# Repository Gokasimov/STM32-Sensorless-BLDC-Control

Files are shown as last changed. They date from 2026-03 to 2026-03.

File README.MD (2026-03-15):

# Sensorless BLDC Motor Controller (STM32G431RBT6)

Motor Demonstration

## 📌 Overview
This repository contains the complete hardware and firmware design for a **Sensorless 6-Step Trapezoidal BLDC Motor Controller** built around the STM32G4 microcontroller. The project demonstrates advanced embedded motor control techniques, including Back-EMF (BEMF) Zero-Crossing Detection (ZCD) via Injected ADCs, hardware-synchronized timers, and a custom-tuned PI speed controller.

The hardware was designed from scratch (KiCad) and tested rigorously to evaluate both physical limits (Voltage Saturation/Kv limits) and embedded software constraints (Timer Quantization limits).

---

## ⚙️ Firmware Architecture & Control Theory

The firmware avoids blocking delays and polling. It relies entirely on a deterministic, interrupt-driven architecture utilizing STM32 Advanced Timers and ADC peripherals.

### 1. Robust State-Machine
The motor control flow is managed by a strict state machine to ensure safe start-up and running conditions:
* **IDLE:** PWM outputs are disabled (Soft Stop / Coasting).
* **ALIGN:** A static DC magnetic field is applied to the stator to force the mechanical rotor into a known starting position.
* **RAMP-UP:** Open-loop commutation with progressively decreasing delay to generate enough initial BEMF for the ADCs to read.
* **CLOSED-LOOP:** Sensorless commutation takes over. The system relies purely on ZCD events and the PI controller manages the PWM duty cycle to reach the target RPM.
* **FAULT:** Emergency hard-stop triggered by stall detection or hardware limits.

### 2. Injected ADC & Timer Synchronization
To avoid high-frequency PWM switching noise (ringing), BEMF is **not** polled continuously in the main loop. Instead, the STM32's **Injected ADC** channels are hardware-triggered by `TIM1`'s Update/Compare events. 
This ensures that the BEMF voltage is sampled exactly at the optimal moment (typically the PWM ON state or center-aligned peak), providing a clean signal for the ZCD algorithm without requiring heavy software filtering.

### 3. PI Speed Control & Super-Sampling (MAF)
Speed calculation at high RPMs suffers from timer resolution limits (Quantization Error). To mitigate this without using floating-point math on every cycle, a **Moving Average Filter (MAF)** is implemented.
The PI controller runs deterministically in a dedicated 1kHz timer interrupt (`TIM7`). It compares the filtered RPM against the target and smoothly adjusts the duty cycle, featuring anti-windup clamping to protect the system.

---

## 🔬 Key Hardware Verifications

Theoretical models were strictly validated against physical hardware behavior using a 4-channel oscilloscope and RAM data logging. *(For full oscilloscope captures, including Dead-Time verification, please see the [Results/](./Results) folder).*

### 1. Hardware RC Filter Phase Shift & ZCD Smoothing
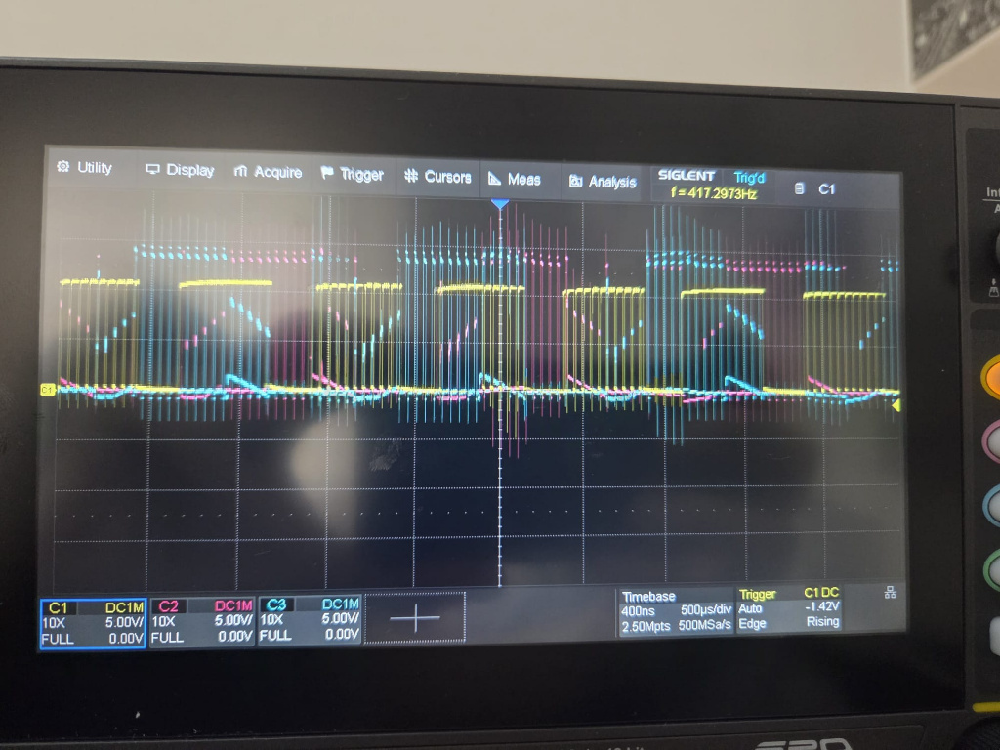
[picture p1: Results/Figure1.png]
ZCD Proof

> **Analysis:** The Yellow trace shows the raw Phase 1 voltage. The Blue trace shows the signal at the STM32 ADC pin after the resistor divider and RC filter. The filter successfully eliminates PWM noise. Crucially, the inherent RC time delay acts as a natural "Phase Advance," optimizing high-speed commutation timing directly in hardware, eliminating the need for 30-degree software compensation.

### 2. System Limit Discovery (RAM Datalogging)
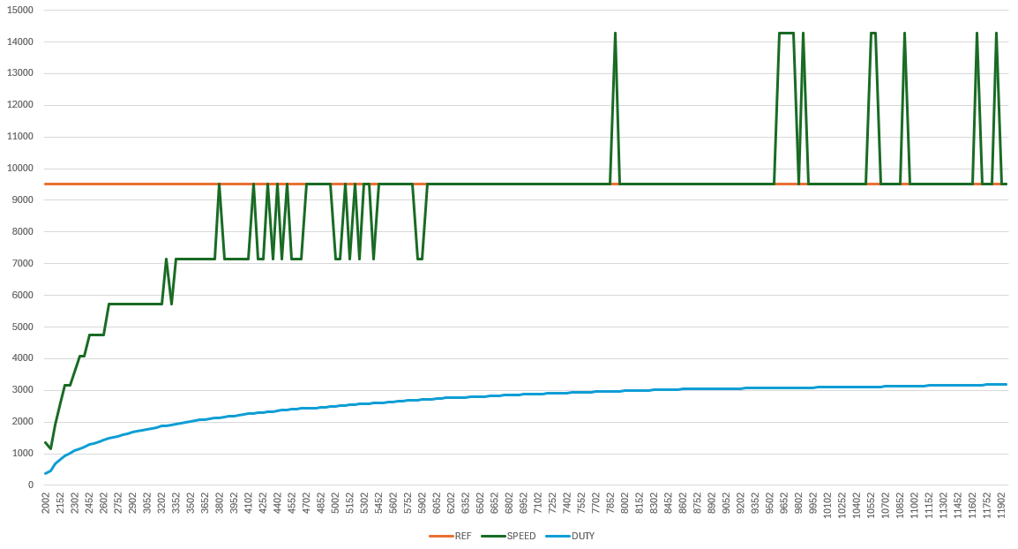
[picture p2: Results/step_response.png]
Step Response

> **Analysis (Step Response & Limitations):** Extracted via an 8KB internal RAM "Flight Recorder" to avoid UART bottlenecking. The graph reveals two physical realities:
> * **Voltage Saturation:** The PI controller pushes the Duty Cycle (Green) to its ~95% limit to reach 14200 RPM, but the motor plateaus at ~9500 RPM (Orange). The motor has hit its BEMF ceiling for a 12V supply ($\Delta V \approx 0$).
> * **Quantization Artifacts:** The step-like jumps at peak speeds are not physical. They are artifacts of the 50us timer resolution; at extreme speeds, a 1-tick variation in commutation measurement results in massive calculated RPM swings, proving the necessity of the MAF implemented in the code.

---

## 🔌 Quick Start & Hardware Setup

### Custom Hardware Notes (v1.0 Prototyping)
* **MP1482 Bypass:** Due to a layout errata on the v1.0 PCB, the onboard 12V-to-3.3V buck converter is bypassed. Logic power is supplied externally. (See `Hardware/ERRATA.md` for details).
* **Future-Proofing (DNP):** The board includes footprints for inline current shunts, op-amps, and encoder headers. These are currently marked as DNP (Do Not Populate) as they are reserved for the upcoming FOC (Field Oriented Control) revision.

## 📁 Repository Structure

📦 STM32-Sensorless-BLDC-Control
 ┣ 📂 Firmware         # STM32CubeIDE Project (C source, headers, .ioc)
 ┣ 📂 Hardware         # KiCad project, Schematics (PDF), BOM, and Errata
 ┣ 📂 Results          # Oscilloscope captures and Step Response graphs
 ┣ 📜 .gitignore       # Excludes IDE debug/build binaries
 ┣ 📜 README.md        # You are here
 ┗ 📜 LICENSE          # MIT License

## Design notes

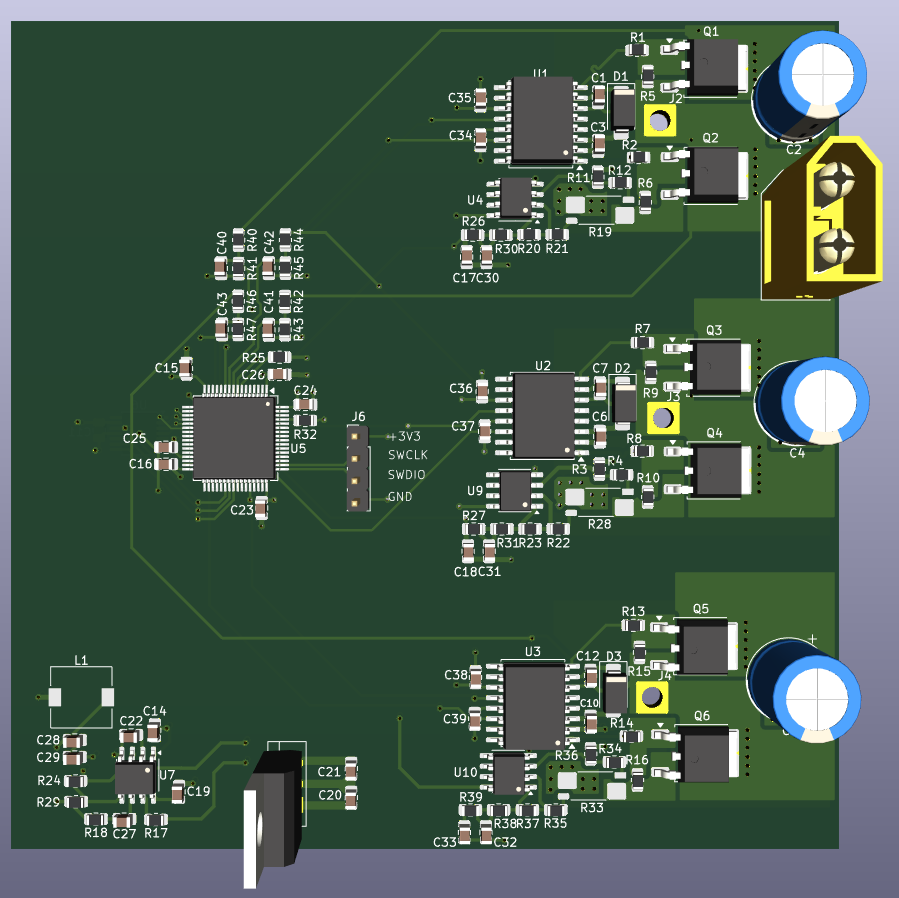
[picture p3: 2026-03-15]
Hardware/Board2_3DView.png

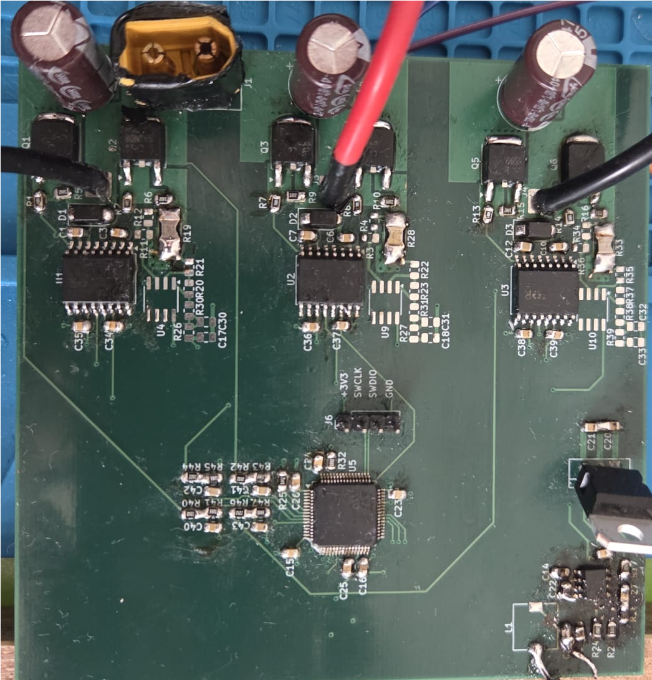
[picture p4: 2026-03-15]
Hardware/Board2.png

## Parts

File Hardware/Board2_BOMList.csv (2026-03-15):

Reference | Qty | Value | Footprint
C1,C7,C12,C20,C21 | 5 | 1uF | Capacitor_SMD:C_0805_2012Metric
C2,C4,C5 | 3 | 470u | Capacitor_THT:CP_Radial_D10.0mm_P5.00mm
C3,C6,C10,C11,C15,C16,C23,C24,C25,C26,C34,C35,C36,C37,C38,C39 | 16 | 0.1uF | Capacitor_SMD:C_0805_2012Metric
C8,C9,C13 | 3 | 1n | Capacitor_SMD:C_0805_2012Metric
C14 | 1 | 10n | Capacitor_SMD:C_0805_2012Metric
C17,C18,C30,C31,C32,C33 | 6 | 33nF | Capacitor_SMD:C_0805_2012Metric
C19 | 1 | 0.1u | Capacitor_SMD:C_0805_2012Metric
C22 | 1 | 10u | Capacitor_SMD:C_0805_2012Metric
C27 | 1 | 3.3n | Capacitor_SMD:C_0805_2012Metric
C28,C29 | 2 | 22n | Capacitor_SMD:C_0805_2012Metric
C40,C41,C42,C43 | 4 | 100n | Capacitor_SMD:C_0805_2012Metric
D1,D2,D3 | 3 | SS14 | Diode_SMD:D_SMA
J1 | 1 | Conn_01x02_Pin | Connector_AMASS:AMASS_XT60-F_1x02_P7.20mm_Vertical
J2,J3,J4 | 3 | Conn_01x01_Pin | Connector_Wire:SolderWire-2sqmm_1x01_D2mm_OD3.9mm
J6 | 1 | Conn_01x04_Pin | Connector_PinHeader_2.54mm:PinHeader_1x04_P2.54mm_Vertical
L1 | 1 | 10u | Inductor_SMD:L_7.3x7.3_H3.5
Q1,Q2,Q3,Q4,Q5,Q6 | 6 | panjit-pjd80n06sa-au | Package_TO_SOT_SMD:TO-252-2
R1,R2,R7,R8,R13,R14 | 6 | 10 | Resistor_SMD:R_0805_2012Metric
R3,R11,R36 | 3 | 22k | Resistor_SMD:R_0805_2012Metric
R4,R12,R21,R22,R34,R35 | 6 | 1k | Resistor_SMD:R_0805_2012Metric
R5,R6,R9,R10,R15,R16,R29 | 7 | 10k | Resistor_SMD:R_0805_2012Metric
R17 | 1 | 100k | Resistor_SMD:R_0805_2012Metric
R18 | 1 | 5.6k | Resistor_SMD:R_0805_2012Metric
R19,R28,R33 | 3 | 5m | Resistor_SMD:R_Shunt_Vishay_WSK2512_6332Metric_T1.19mm
R20,R23,R37 | 3 | 24k | Resistor_SMD:R_0805_2012Metric
R24 | 1 | 26.1k | Resistor_SMD:R_0805_2012Metric
R25,R32 | 2 | 10K | Resistor_SMD:R_0805_2012Metric
R26,R27,R39 | 3 | 270 | Resistor_SMD:R_0805_2012Metric
R30,R31,R38 | 3 | 22 | Resistor_SMD:R_0805_2012Metric
R40,R42,R44,R46 | 4 | 22K | Resistor_SMD:R_0805_2012Metric
R41,R43,R45,R47 | 4 | 3.3K | Resistor_SMD:R_0805_2012Metric
U1,U2,U3 | 3 | IR2110S | Package_SO:SOIC-16W_7.5x10.3mm_P1.27mm
U4,U9,U10 | 3 | TLV9062 | Package_SO:SOIC-8_3.9x4.9mm_P1.27mm | DNP
U5 | 1 | STM32G431RBT6 | Package_QFP:LQFP-64_10x10mm_P0.5mm
U6 | 1 | AS5047D | Package_SO:TSSOP-14_4.4x5mm_P0.65mm | DNP
U7 | 1 | MP1482DS-LF-Z | Package_SO:SOIC-8_3.9x4.9mm_P1.27mm
U8 | 1 | LM7812_TO220 | Package_TO_SOT_THT:TO-220-3_Vertical

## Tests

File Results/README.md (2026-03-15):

# Hardware Verification and Oscilloscope Measurements

This directory contains the raw hardware validation data for the v1.0 Sensorless BLDC controller. Measurements were taken using a 4-channel Siglent SDS814X oscilloscope.

### 1. 3-Phase Commutation Waveforms
3 Phase Commutation
> **Figure 1:** The oscilloscope capture demonstrates the successful 6-step trapezoidal control of the BLDC motor. The 120-degree electrical phase shift is clearly visible. PWM chopping is active during the ON states, while the un-driven phase clearly shows the rising and falling slopes of the Back-EMF, confirming a healthy sensorless operation.

### 2. Hardware RC Filter Phase Shift & ZCD Smoothing
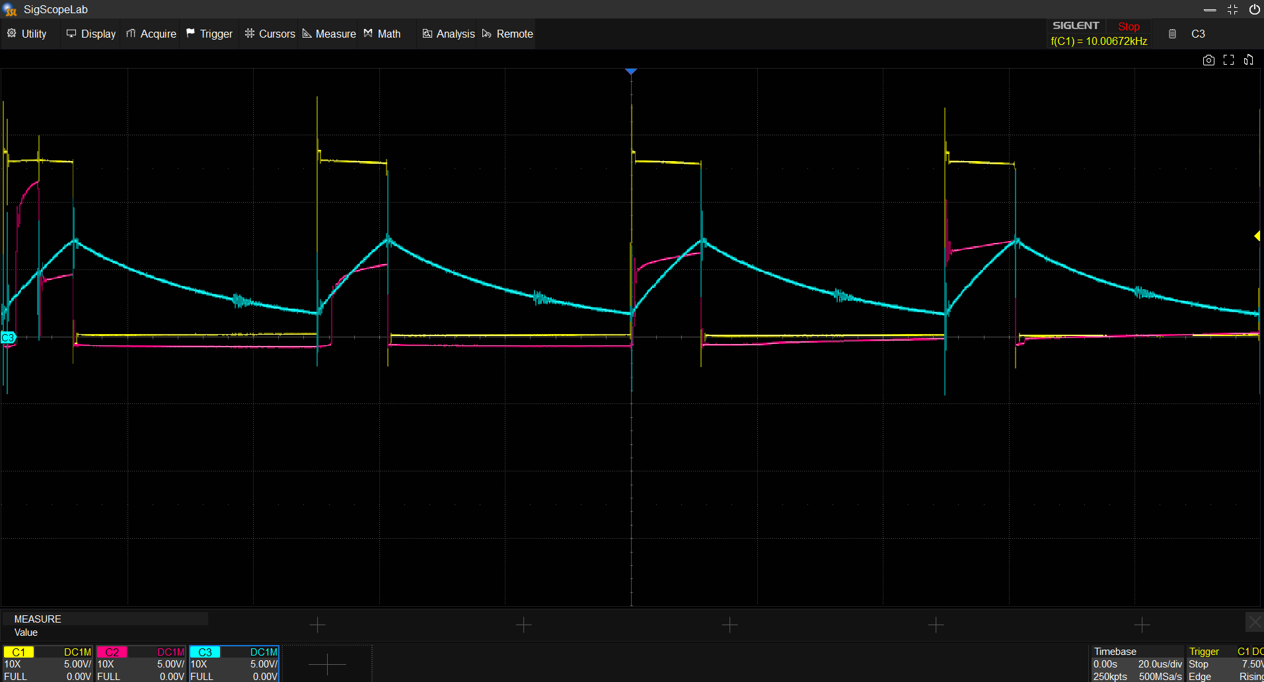
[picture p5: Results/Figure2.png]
ZCD Proof

> **Figure 2:** Yellow trace shows the raw Phase 1 voltage with high-frequency PWM switching. The Blue trace shows the signal at the STM32 ADC pin after the resistor divider and RC filter. The filter successfully eliminates PWM noise, providing a clean BEMF zero-crossing point. The inherent RC time delay acts as a natural "Phase Advance," optimizing high-speed commutation timing without requiring extra MCU processing overhead.

### 3. Hardware Dead-Time Insertion
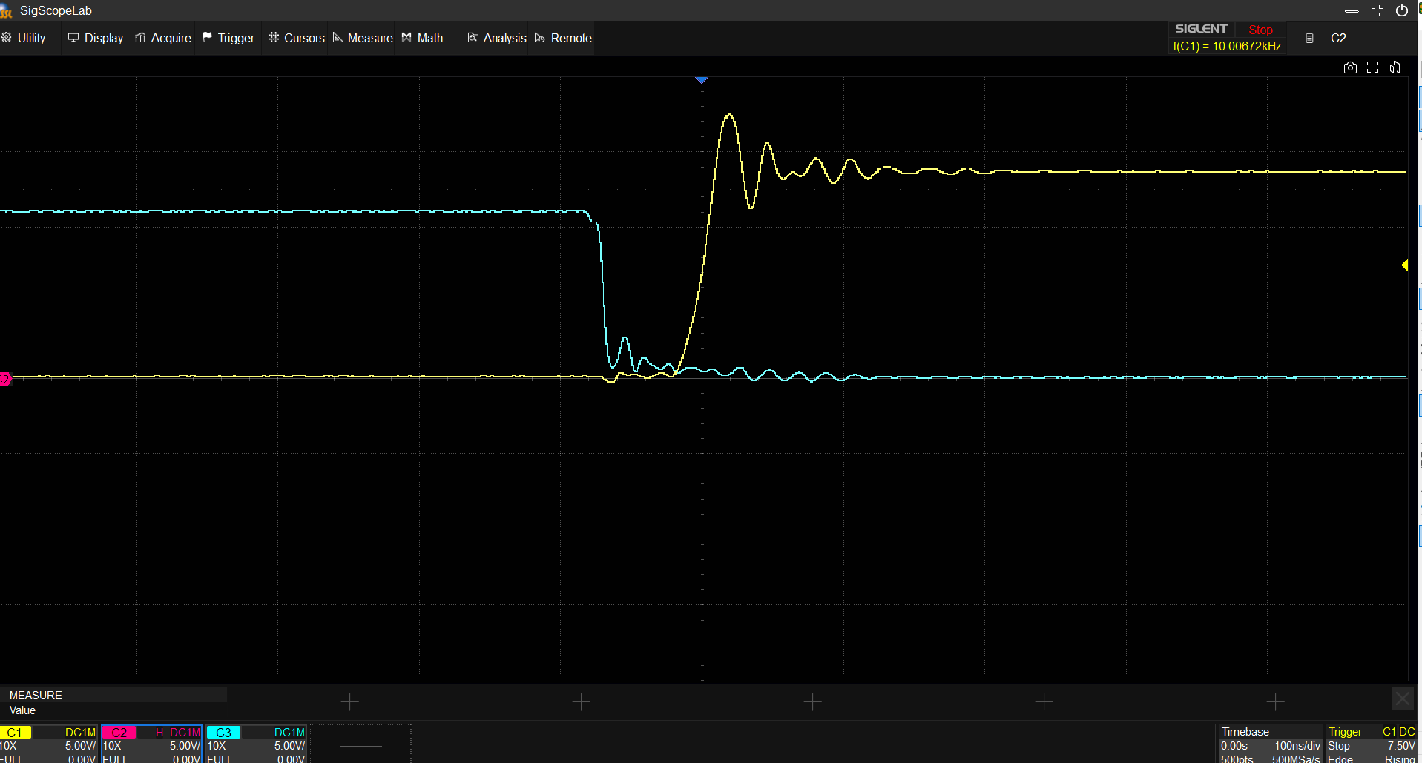
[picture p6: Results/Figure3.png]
Dead Time

> **Figure 3:** Captured at a 100ns/div timebase, this image verifies the STM32 Advanced Timer (TIM1) dead-time generation. A crucial ~100ns gap is maintained between the turn-off of one state and the turn-on of the next. This strictly prevents shoot-through currents in the half-bridges, ensuring the gate drivers and power MOSFETs operate within safe thermal limits.

### 4. BEMF Voltage Saturation at Maximum RPM
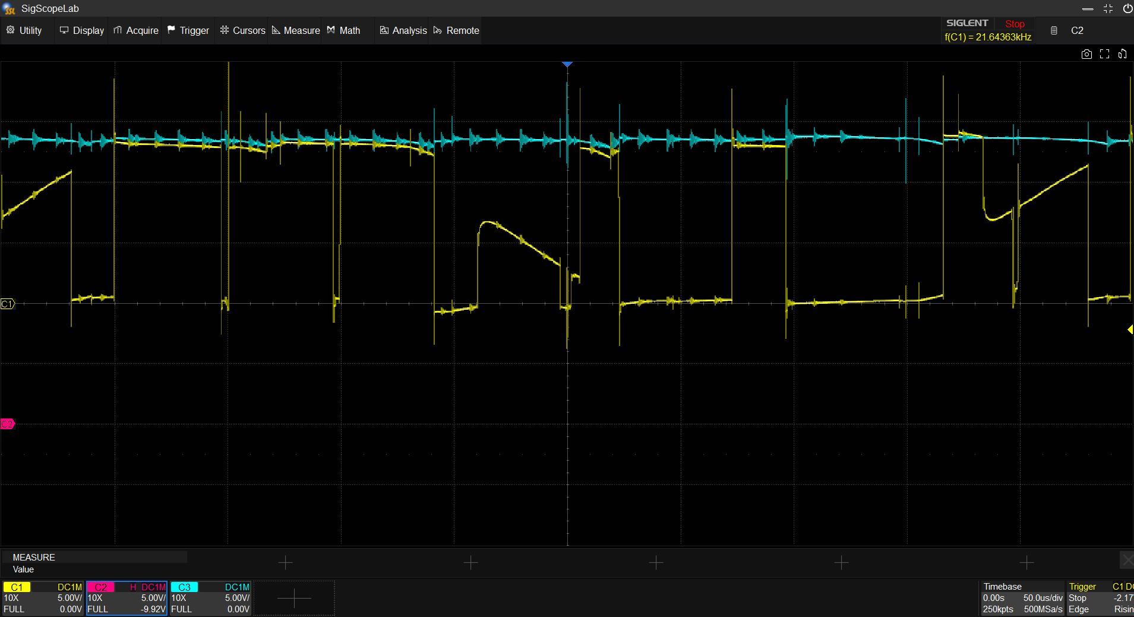
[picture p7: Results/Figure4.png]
Voltage Saturation

> **Figure 4:** The Yellow trace (Phase 1 BEMF) peak approaches the Blue trace (12V DC Link Supply). This proves that the PI controller has saturated the PWM duty cycle to its maximum limit. The motor has reached its physical Kv ceiling for a 12V supply; further acceleration is impossible as ΔV ≈ 0.

### 5. Step Response and System Limit Analysis (RAM Datalog)
Step Response
> **Figure 5: Closed-Loop Telemetry Data Extracted via RAM Datalogging.**
> This plot reveals two critical system boundaries:
> 1. **Voltage Saturation (Physical Limit):** The PI controller smoothly ramps the Duty Cycle (Green) to its absolute maximum (~95%) trying to reach the 14200 RPM reference (Blue). However, the actual speed (Orange) plateaus at ~9500 RPM. This perfectly corroborates the oscilloscope measurement in Figure 4; the motor has hit its 12V BEMF ceiling.
> 2. **Quantization Limit (Software Limit):** The step-like nature of the RPM curve and the high-frequency spikes at the end are not mechanical oscillations. They are artifacts of Timer resolution (Quantization Error). At extreme speeds, the commutation period drops to merely 2 or 3 timer ticks (50us/tick). A variation of just 1 tick (due to ZCD noise) causes the calculated RPM to jump drastically (e.g., 28571/3 = 9523 RPM vs 28571/2 = 14285 RPM).

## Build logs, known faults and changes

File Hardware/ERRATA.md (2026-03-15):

# Hardware Errata and Implementation Notes (v1.0 Prototype)

This document outlines the known hardware issues, temporary workarounds, and unpopulated components for the v1.0 revision of the Sensorless BLDC Motor Controller board. 

As this is an initial lab-tested R&D prototype, some sections have been modified post-production to ensure stable operation of the core motor control algorithms.

## 1. MP1482 Buck Converter Circuit (Bypassed)
* **Description:** A layout/design error was identified in the onboard MP1482 step-down converter section during the initial board bring-up.
* **Workaround:** The onboard voltage regulation section is currently bypassed to prevent power instability. System logic voltage (3.3V for MCU) is temporarily provided via external laboratory power supplies using direct flying leads (bodge wires) soldered to the respective power planes.
* **Impact:** This issue only affects the standalone power capability of the board. It does **not** affect the MCU performance, gate driver switching logic, or the BEMF sensing circuitry. The sensorless 6-step commutation algorithms function perfectly under this bypassed configuration.
* **Resolution:** The buck converter layout will be completely revised in the v1.1 hardware update.

## 2. DNP (Do Not Populate) Components - Future FOC Prep
* **Description:** The PCB was strategically designed to be forward-compatible with advanced motor control techniques. It includes footprints for phase current sensing (inline/low-side shunt resistors and operational amplifiers) as well as header pins for quadrature encoders.
* **Current Status:** Since this specific repository focuses entirely on **Sensorless 6-Step Trapezoidal Control** utilizing Back-EMF Zero-Crossing Detection (ZCD), these specific components are intentionally left unpopulated (DNP) to reduce noise and BOM cost.
* **Future Use:** These analog measurement sections are reserved and will be populated for the upcoming Field Oriented Control (FOC) phase of the project.

## 3. General Prototyping Notes
* Visible flux residues and external wire modifications on the physical board are normal artifacts of the debugging and tuning process for this v1.0 iteration. The primary focus of this hardware version is to validate the STM32G4's ADC Injected Conversion, Timer synchronizations, and hardware limits.

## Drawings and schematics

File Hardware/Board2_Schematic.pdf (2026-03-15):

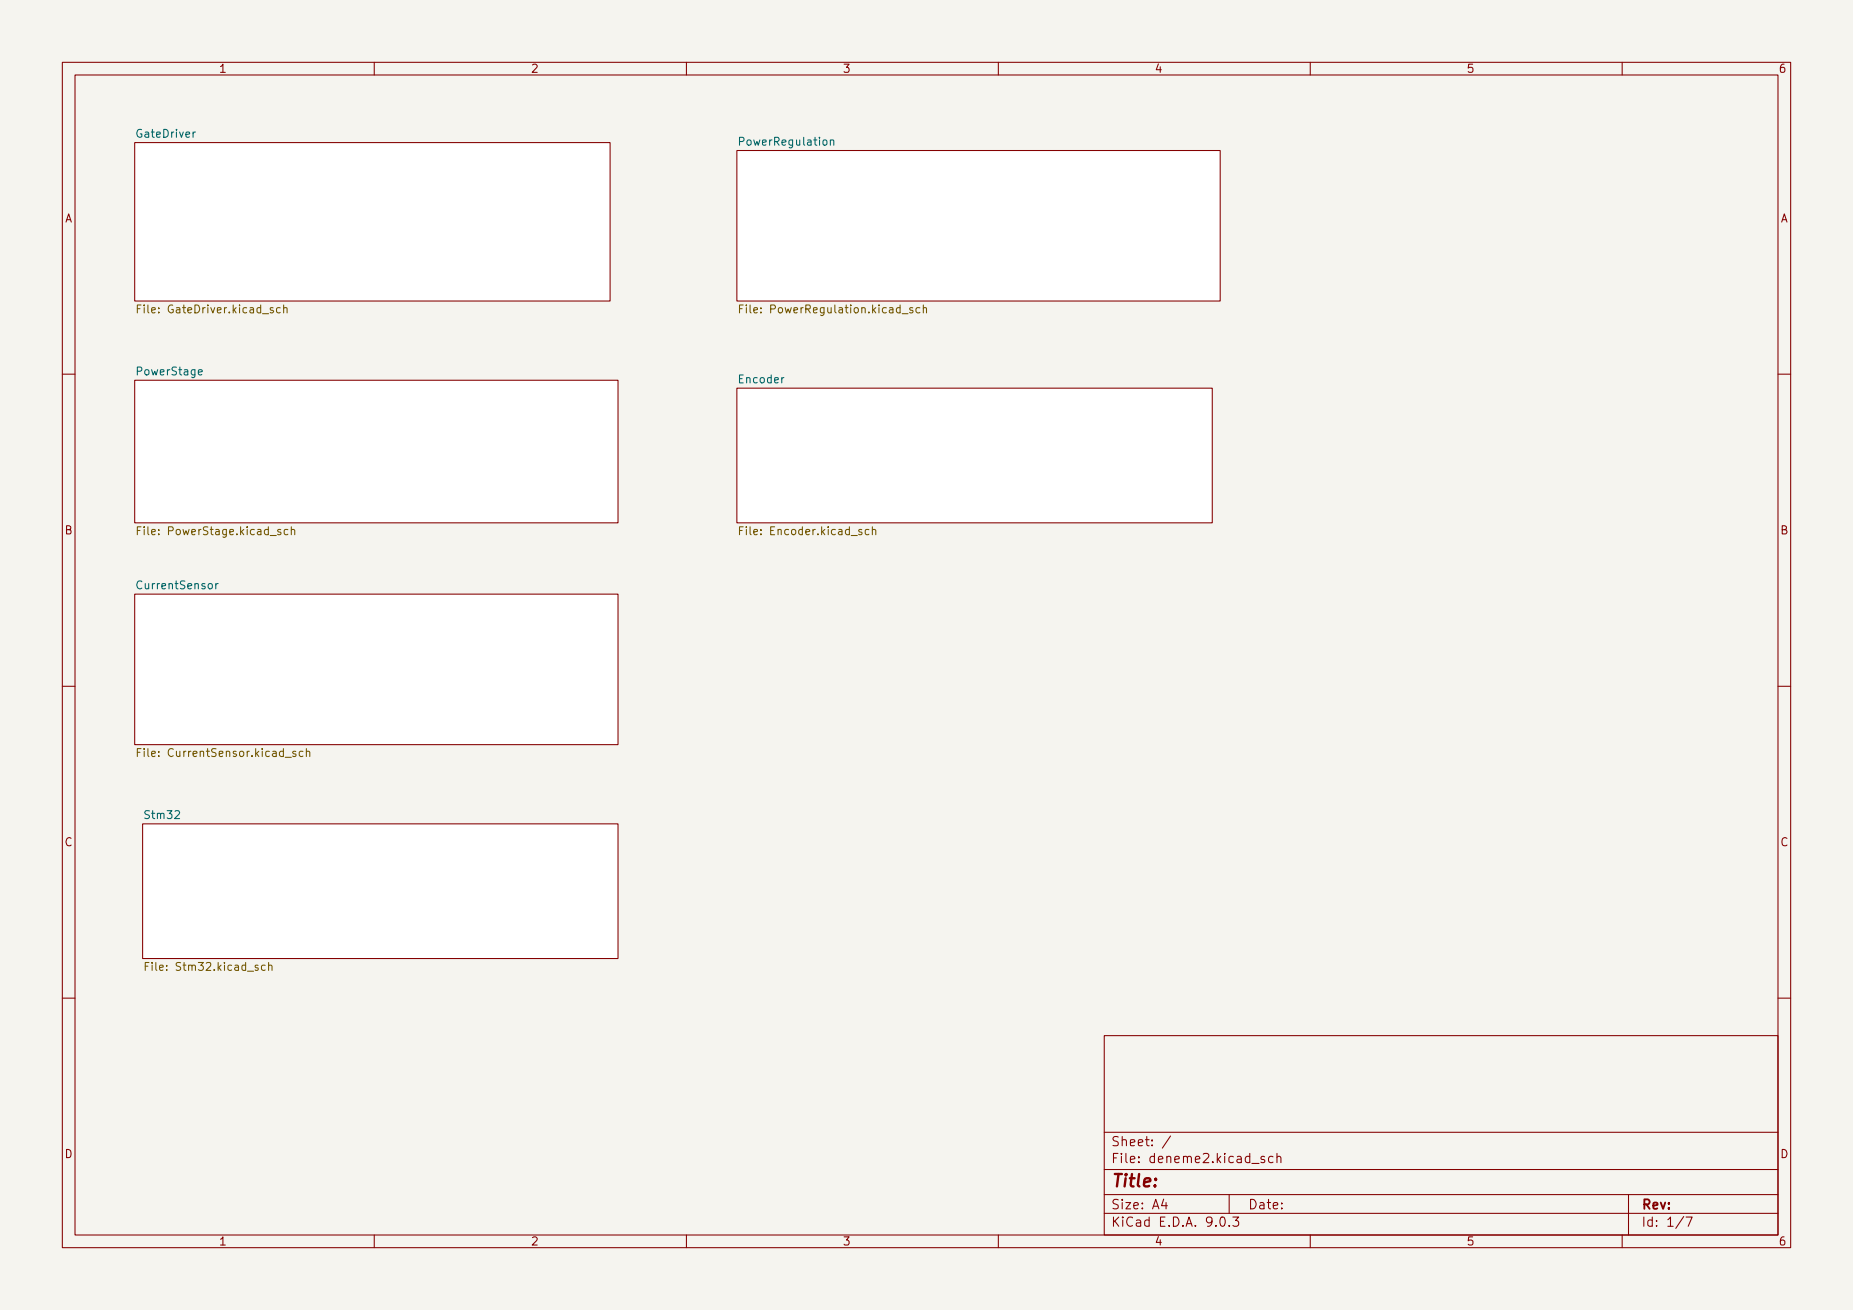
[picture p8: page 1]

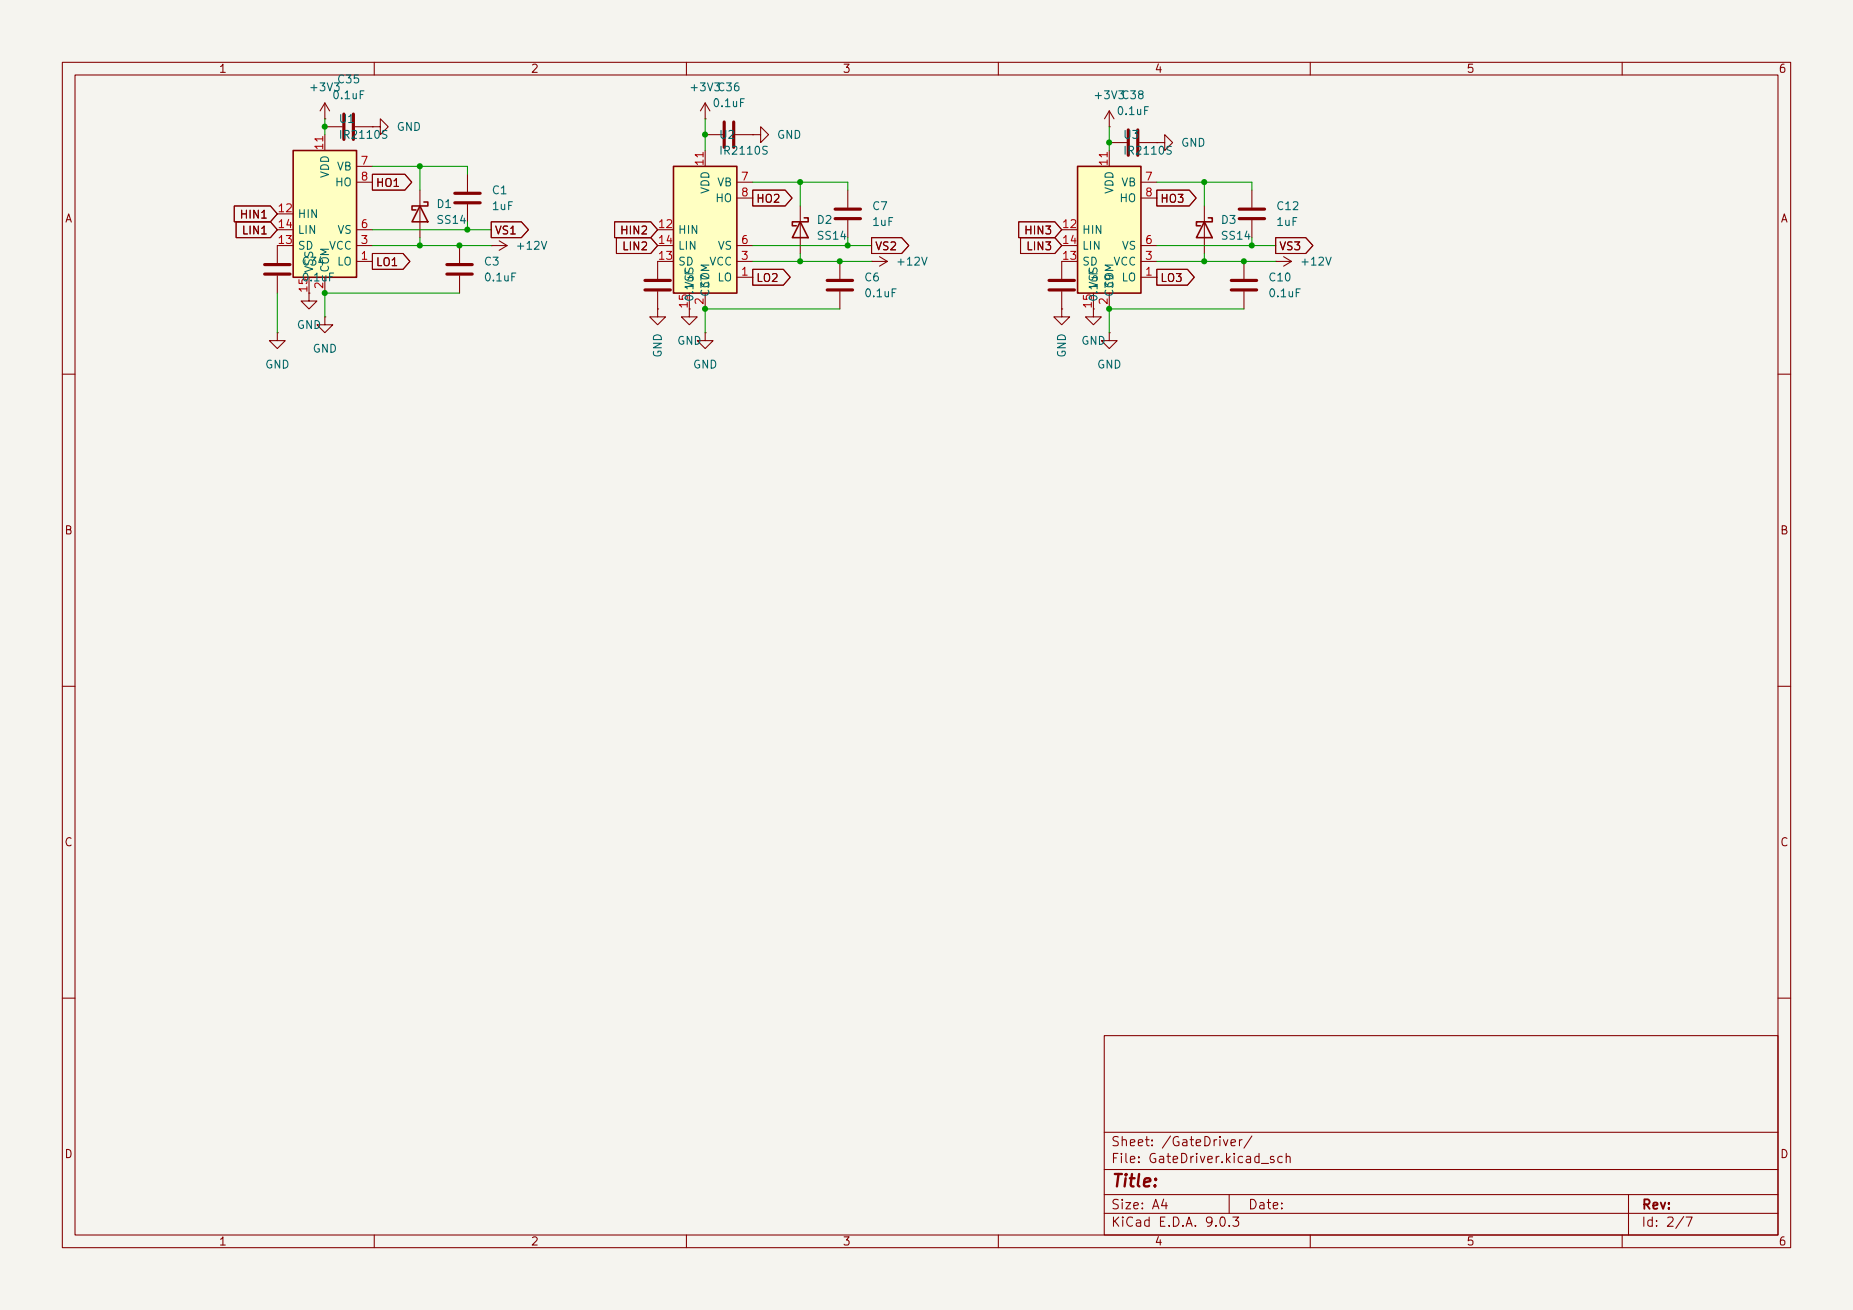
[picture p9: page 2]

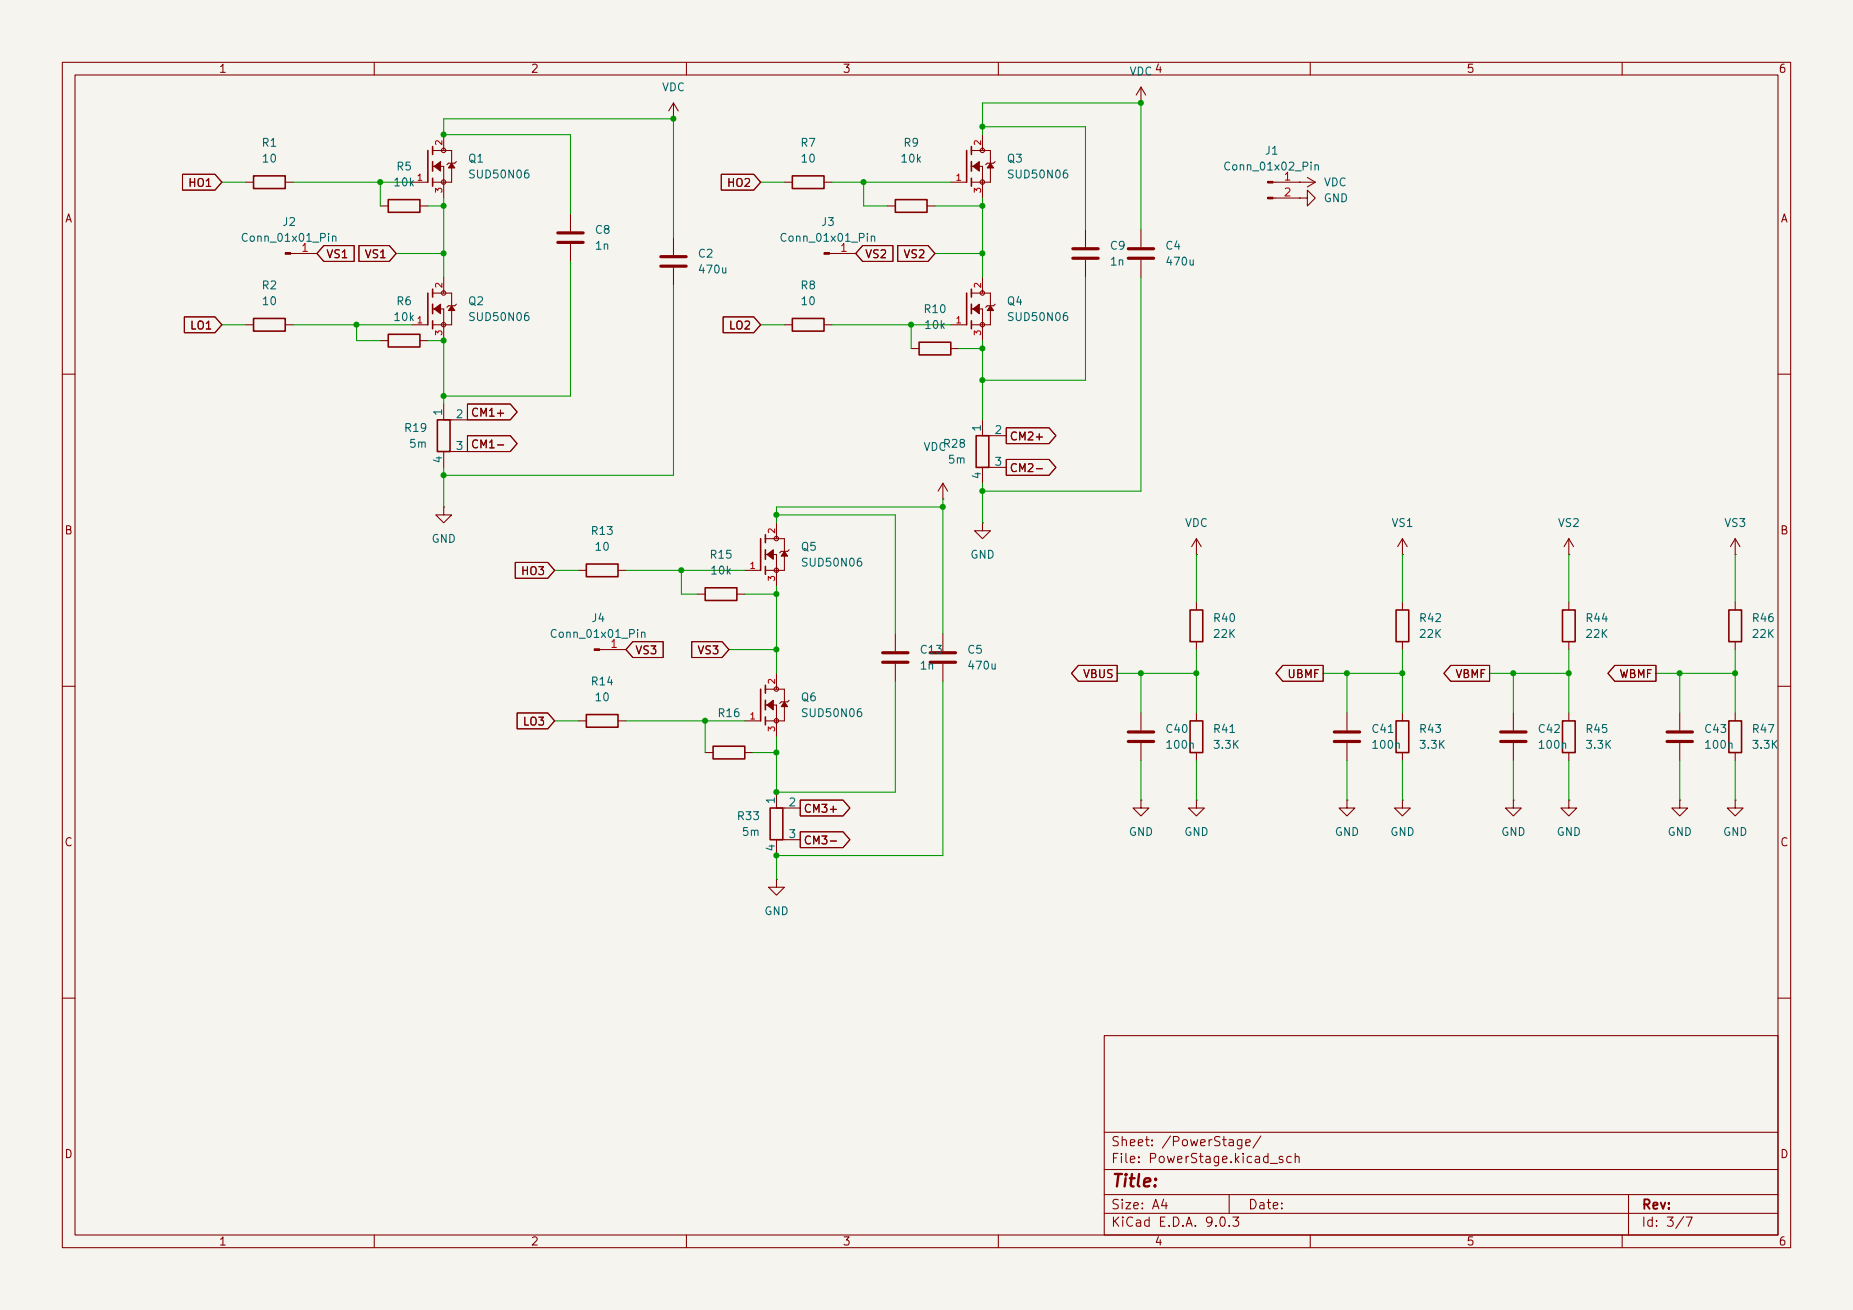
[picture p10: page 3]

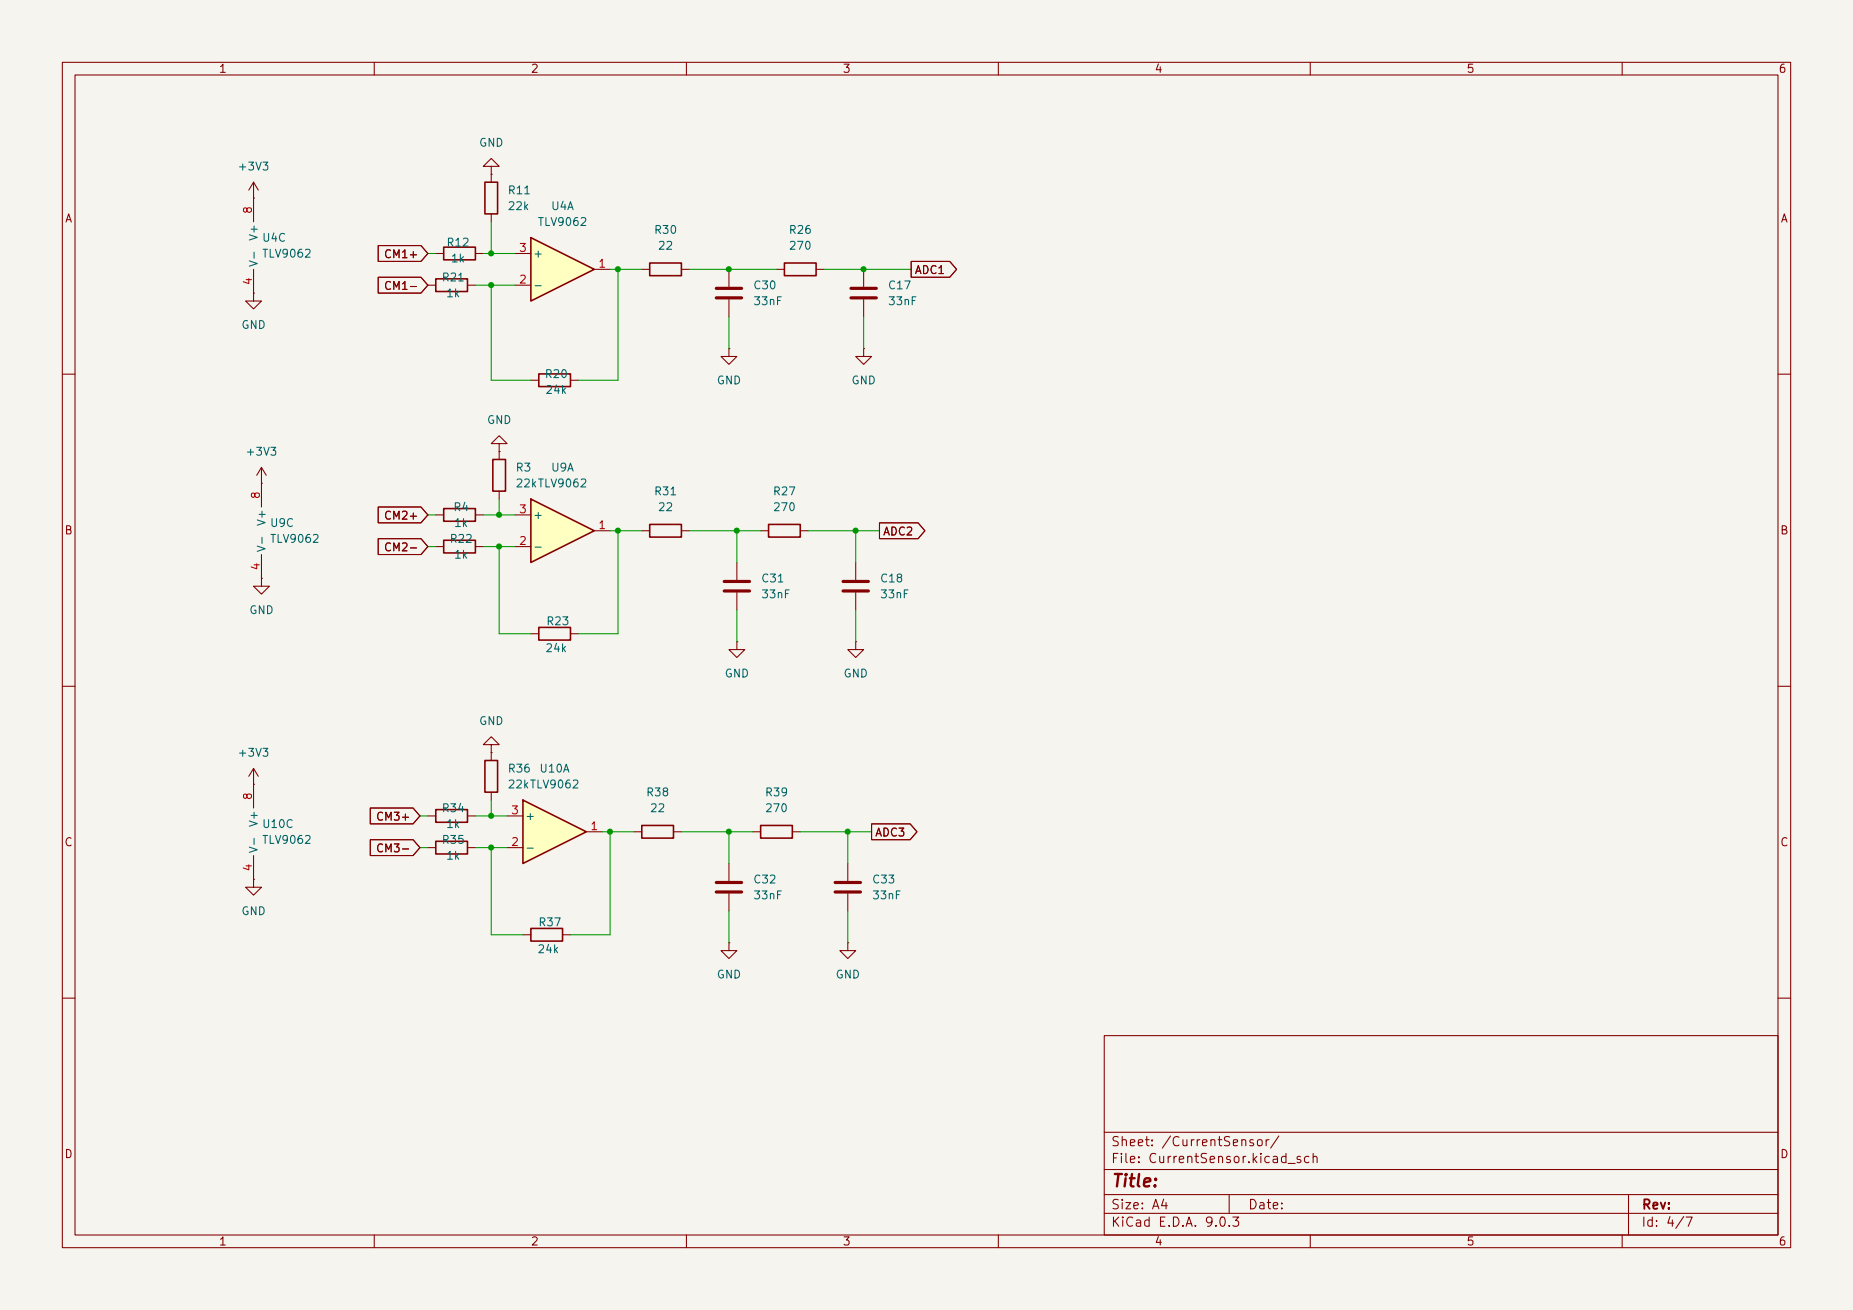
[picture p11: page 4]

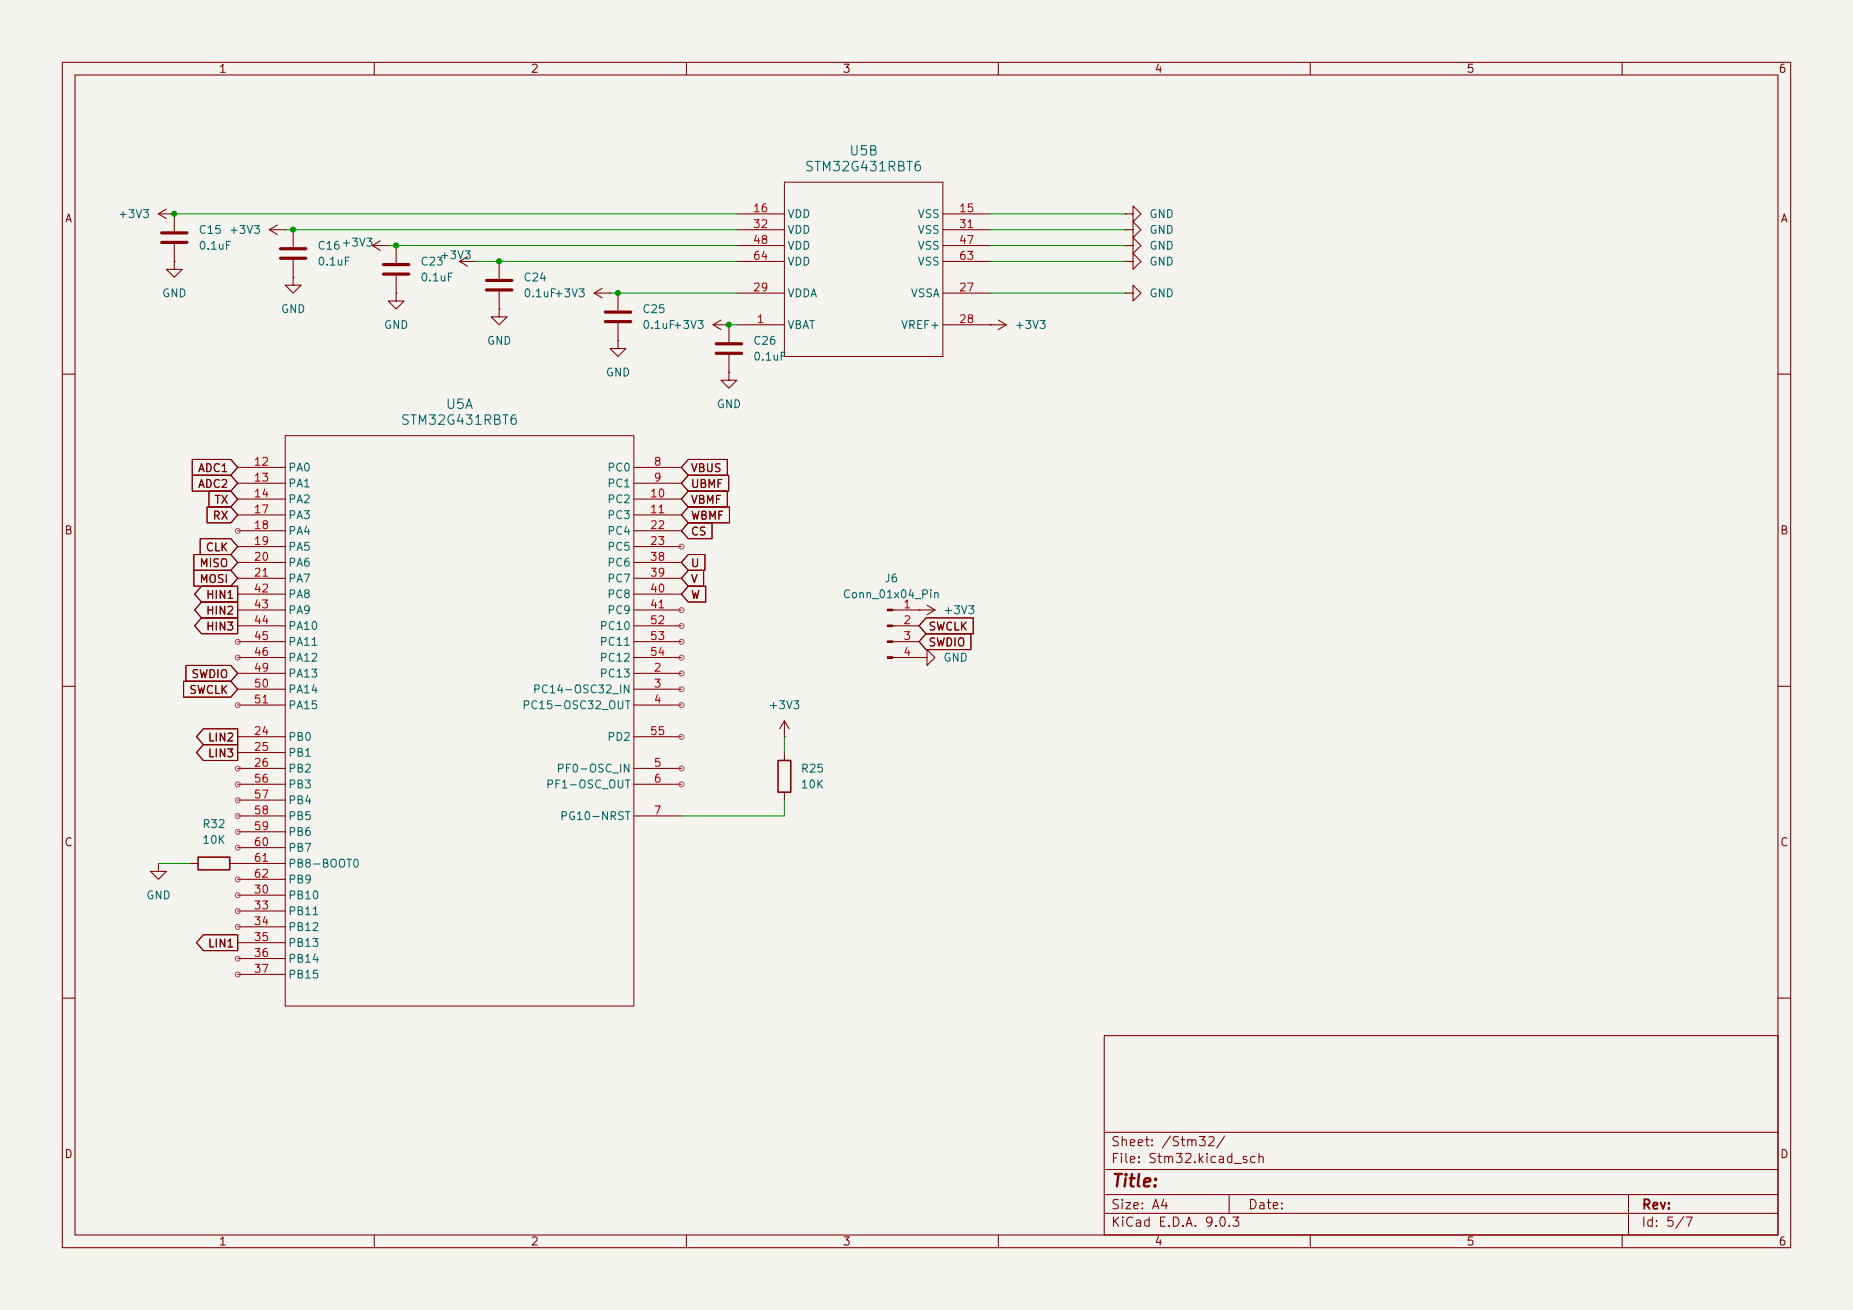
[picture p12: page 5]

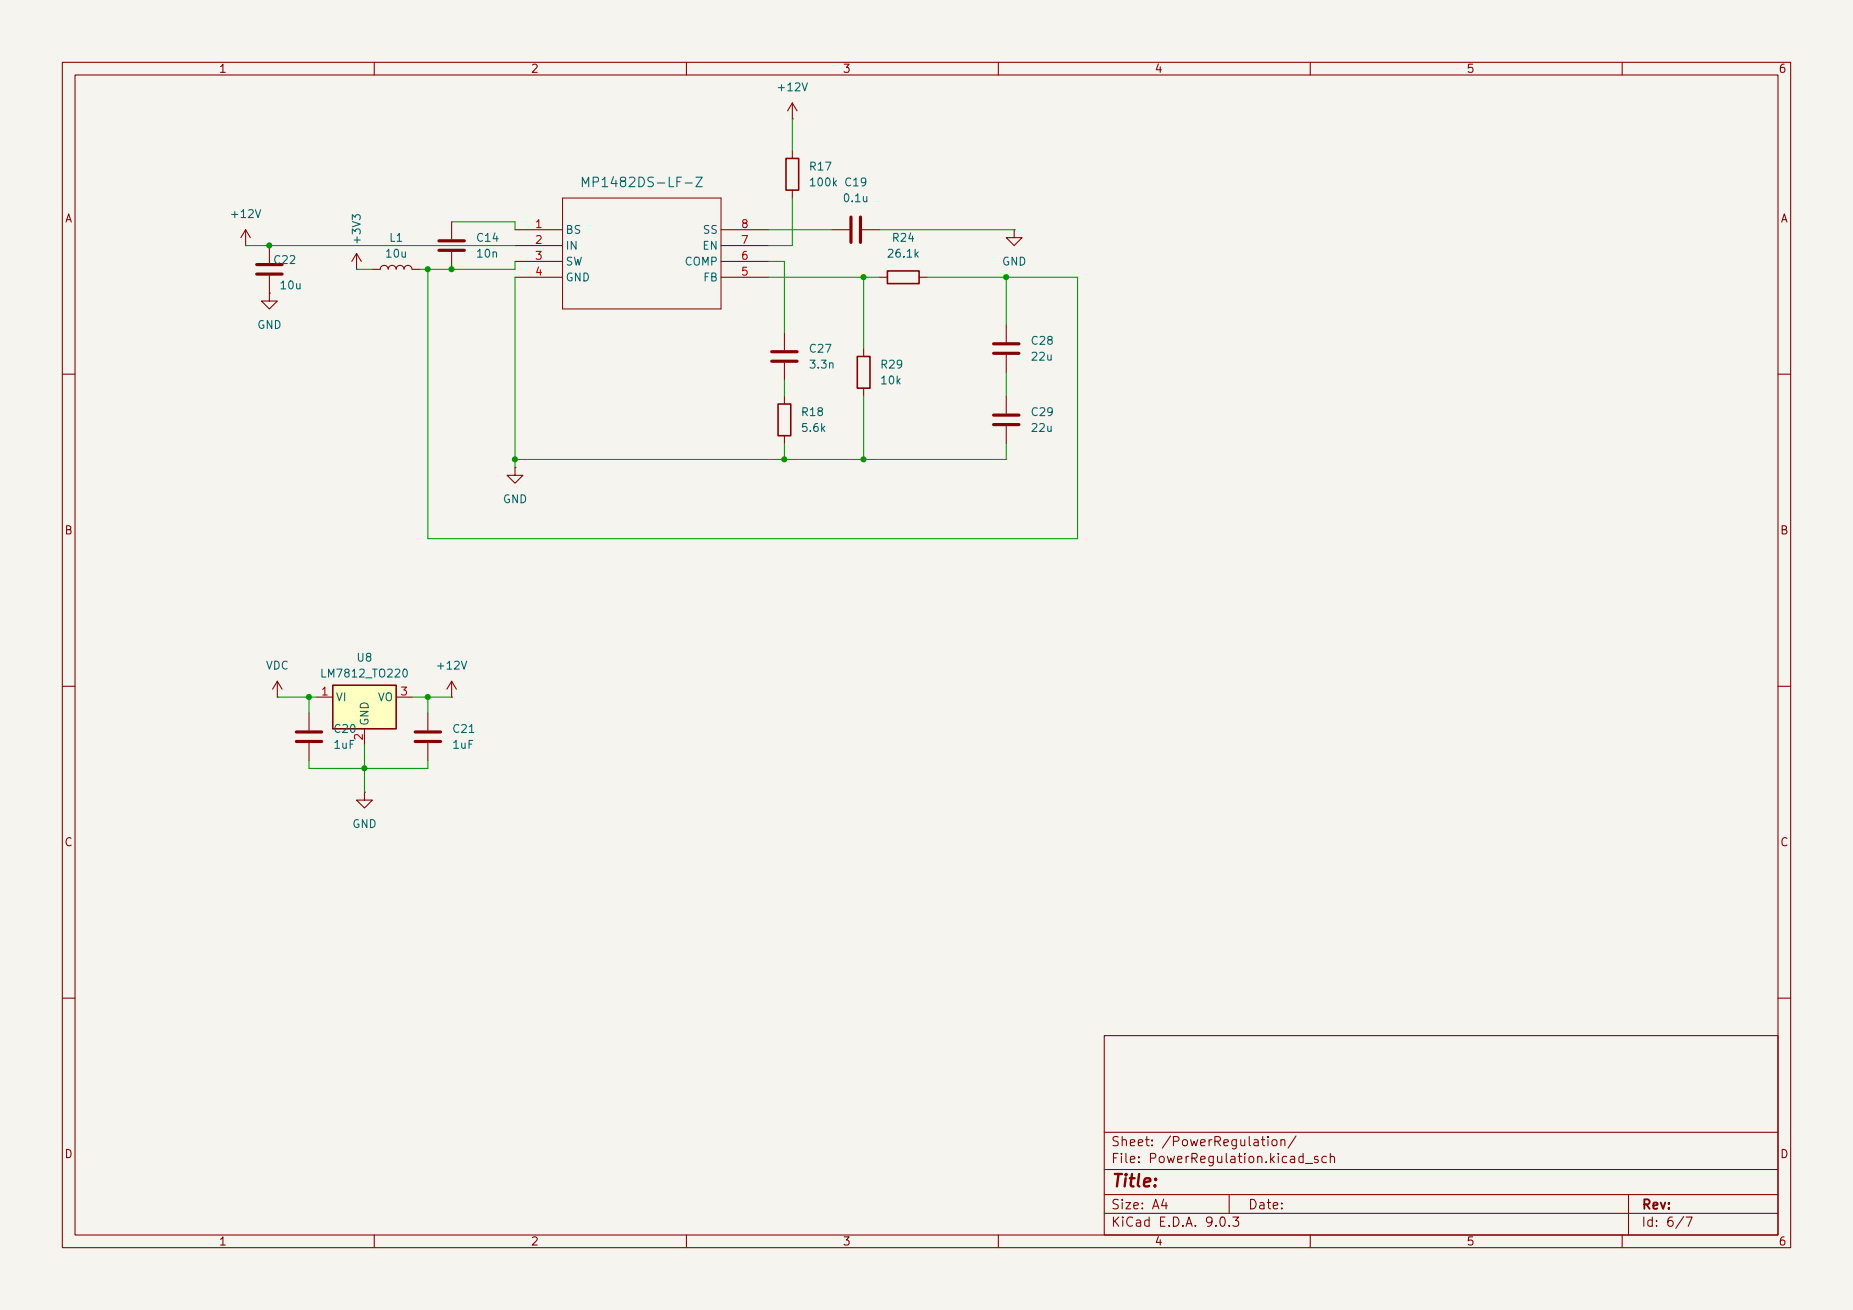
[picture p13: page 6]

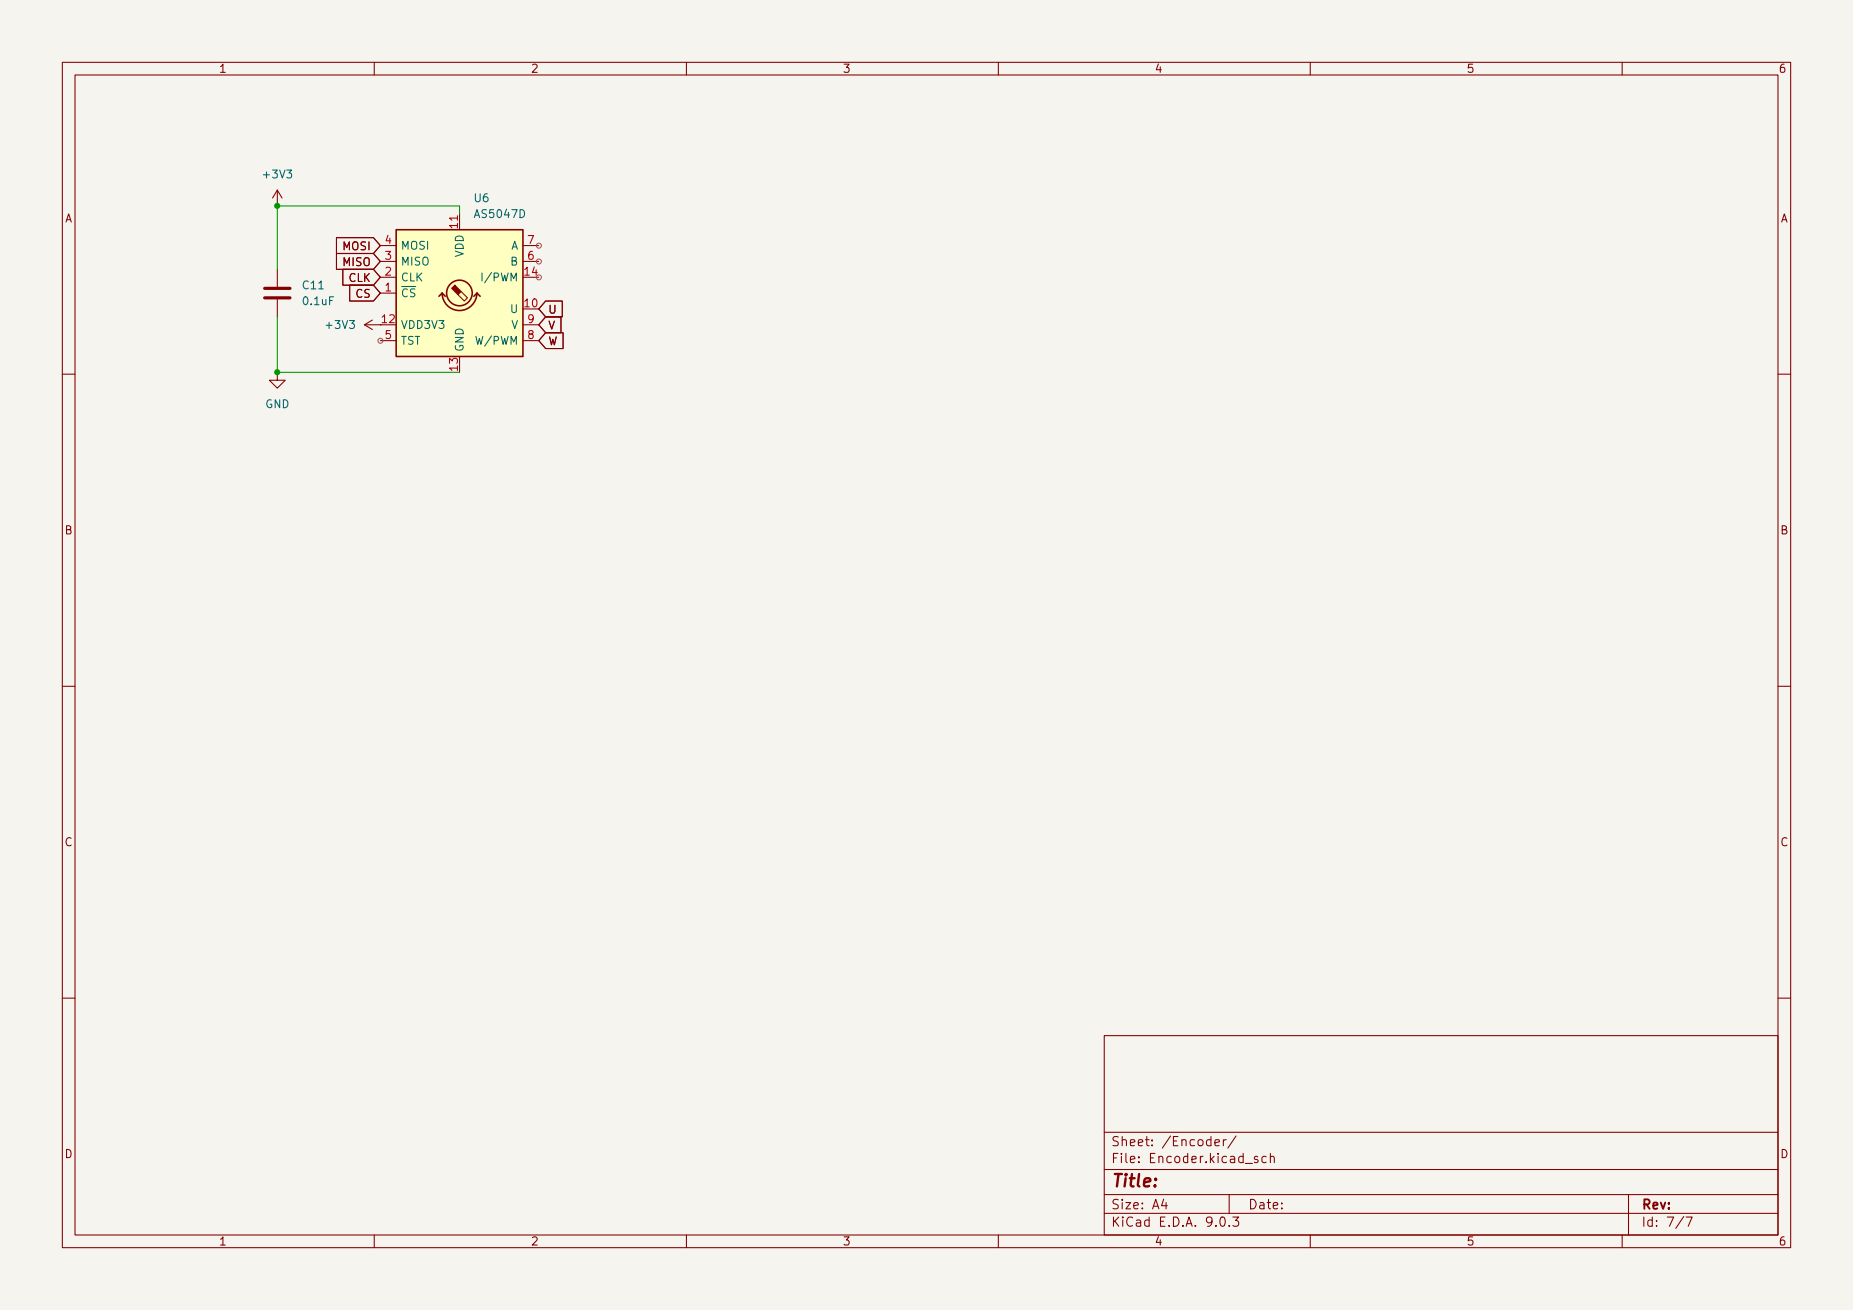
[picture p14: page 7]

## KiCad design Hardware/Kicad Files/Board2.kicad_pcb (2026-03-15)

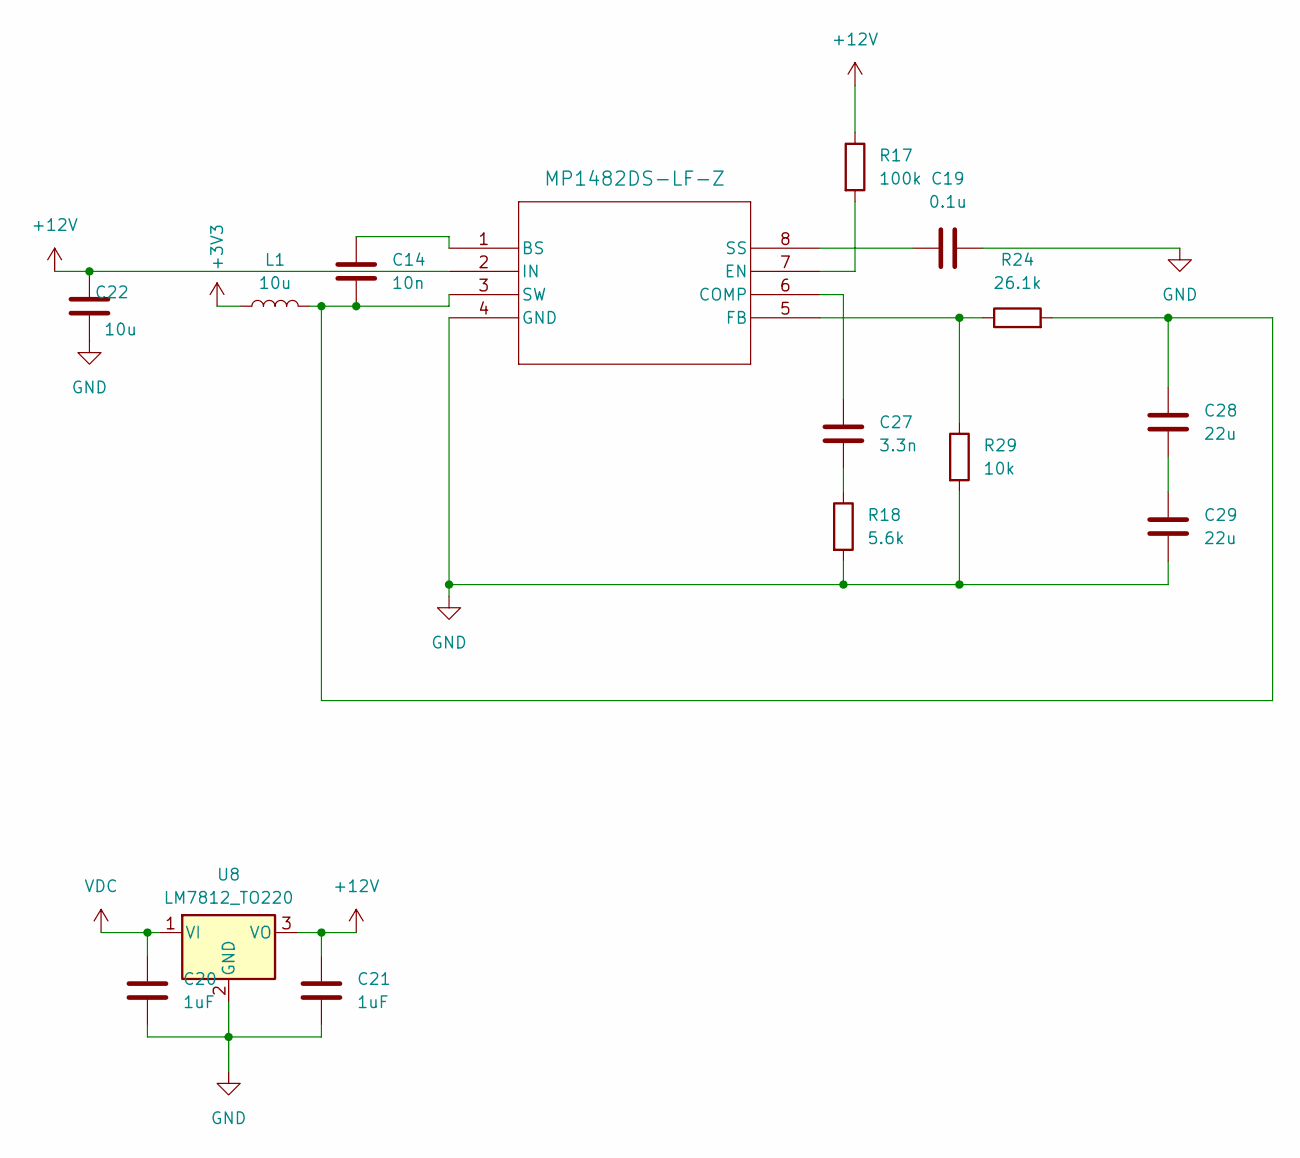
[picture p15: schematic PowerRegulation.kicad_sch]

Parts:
C14: 10n; C_0805_2012Metric
C19: 0.1u; C_0805_2012Metric
C20, C21: 1uF; C_0805_2012Metric
C22: 10u; C_0805_2012Metric
C27: 3.3n; C_0805_2012Metric
C28, C29: 22u; C_0805_2012Metric
L1: 10u; L_7.3x7.3_H3.5
R17: 100k; R_0805_2012Metric
R18: 5.6k; R_0805_2012Metric
R24: 26.1k; R_0805_2012Metric
R29: 10k; R_0805_2012Metric
U7: MP1482DS-LF-Z; SOIC-8_3.9x4.9mm_P1.27mm
U8: LM7812_TO220; TO-220-3_Vertical

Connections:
+3V3: L1.1; also elsewhere on the board
+12V: C21.1, C22.2, R17.1, U7.2 (IN), U8.3 (VO); also elsewhere on the board
GND: C19.2, C20.2, C21.2, C22.1, C29.1, R18.2, R29.2, U7.4 (GND), U8.2 (GND); also elsewhere on the board
unnamed: C27.1, R18.1
unnamed: C28.1, C29.2
unnamed: C14.1, U7.1 (BS)
unnamed: C27.2, U7.6 (COMP)
unnamed: R17.2, U7.7 (EN)
unnamed: R24.1, R29.1, U7.5 (FB)
unnamed: C19.1, U7.8 (SS)
unnamed: C14.2, C28.2, L1.2, R24.2, U7.3 (SW)
VDC: C20.1, U8.1 (VI); also elsewhere on the board

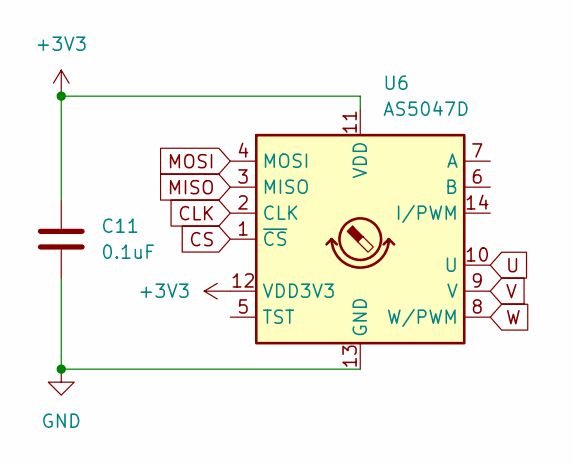
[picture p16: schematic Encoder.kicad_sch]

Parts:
C11: 0.1uF; C_0805_2012Metric
U6: AS5047D; TSSOP-14_4.4x5mm_P0.65mm

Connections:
+3V3: C11.1, U6.11 (VDD), U6.12 (VDD3V3); also elsewhere on the board
CLK: U6.2 (CLK); also elsewhere on the board
CS: U6.1 (~CS); also elsewhere on the board
GND: C11.2, U6.13 (GND); also elsewhere on the board
MISO: U6.3 (MISO); also elsewhere on the board
MOSI: U6.4 (MOSI); also elsewhere on the board
U: U6.10 (U); also elsewhere on the board
V: U6.9 (V); also elsewhere on the board
W: U6.8 (W/PWM); also elsewhere on the board

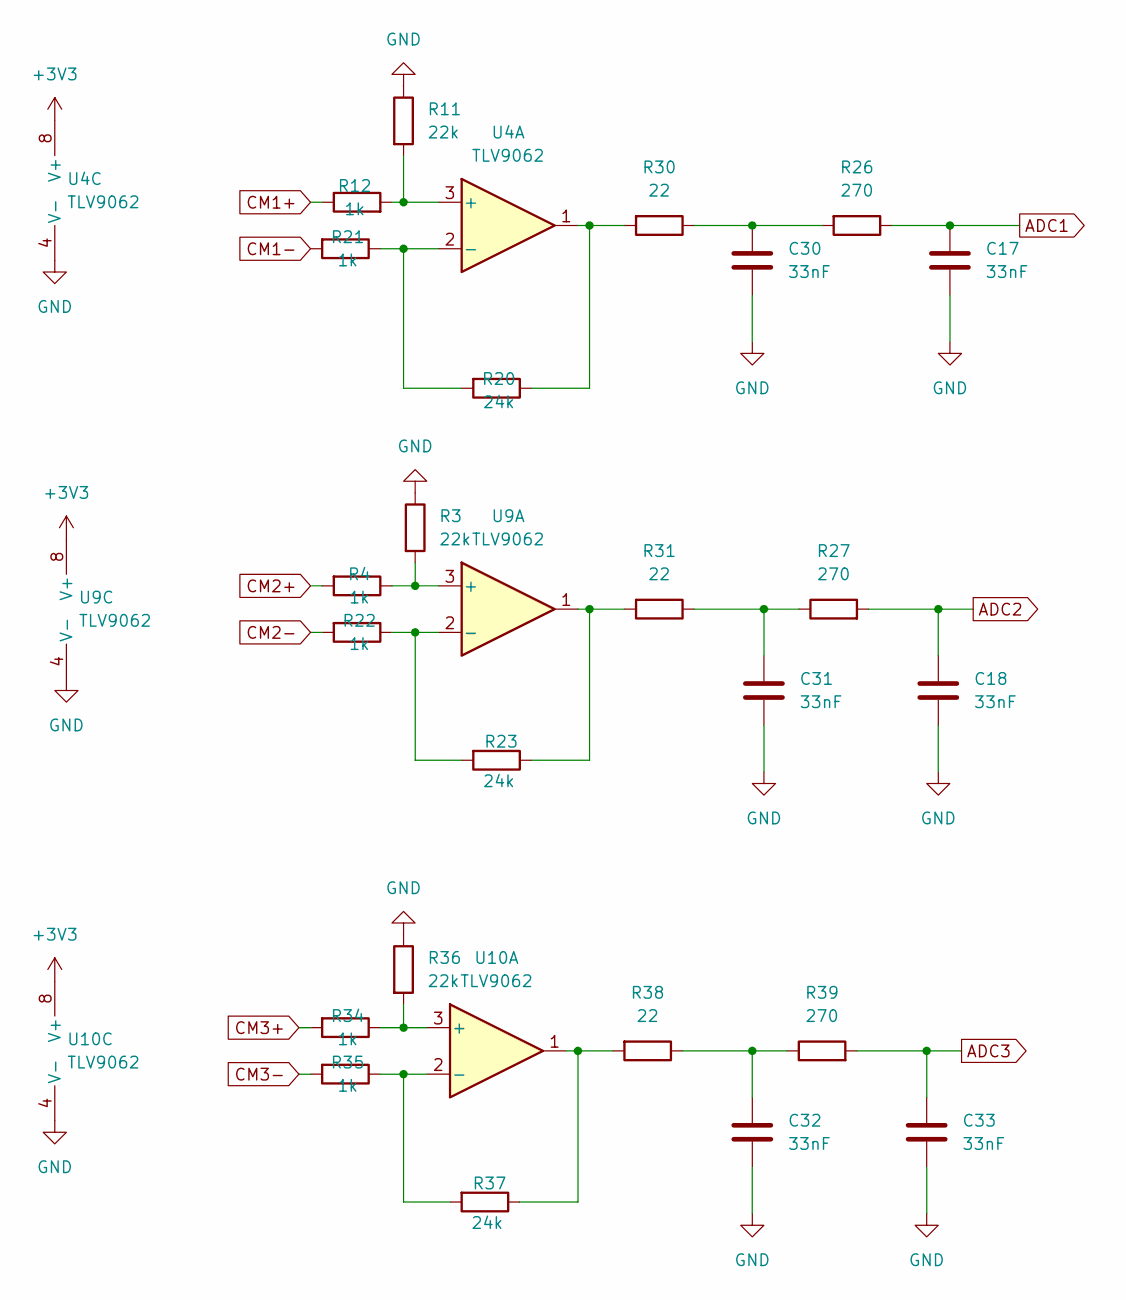
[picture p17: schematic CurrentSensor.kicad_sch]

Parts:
C17, C18, C30, C31, C32, C33: 33nF; C_0805_2012Metric
R3, R11, R36: 22k; R_0805_2012Metric
R4, R12, R21, R22, R34, R35: 1k; R_0805_2012Metric
R20, R23, R37: 24k; R_0805_2012Metric
R26, R27, R39: 270; R_0805_2012Metric
R30, R31, R38: 22; R_0805_2012Metric
U4, U9, U10: TLV9062; SOIC-8_3.9x4.9mm_P1.27mm

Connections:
+3V3: U4.8 (V+), U9.8 (V+), U10.8 (V+); also elsewhere on the board
ADC1: C17.1, R26.1; also elsewhere on the board
ADC2: C18.2, R27.2; also elsewhere on the board
ADC3: C33.2, R39.2
CM1+: R12.1; also elsewhere on the board
CM1-: R21.2; also elsewhere on the board
CM2+: R4.2; also elsewhere on the board
CM2-: R22.2; also elsewhere on the board
CM3+: R34.2; also elsewhere on the board
CM3-: R35.2; also elsewhere on the board
GND: C17.2, C18.1, C30.2, C31.2, C32.2, C33.1, R3.1, R11.1, R36.1, U4.4 (V-), U9.4 (V-), U10.4 (V-); also elsewhere on the board
unnamed: C30.1, R26.2, R30.1
unnamed: C31.1, R27.1, R31.1
unnamed: C32.1, R38.1, R39.1
unnamed: R20.1, R30.2, U4.1
unnamed: R23.1, R31.2, U9.1
unnamed: R37.1, R38.2, U10.1
unnamed: R11.2, R12.2, U4.3 (+)
unnamed: R20.2, R21.1, U4.2 (-)
unnamed: R3.2, R4.1, U9.3 (+)
unnamed: R22.1, R23.2, U9.2 (-)
unnamed: R34.1, R36.2, U10.3 (+)
unnamed: R35.1, R37.2, U10.2 (-)

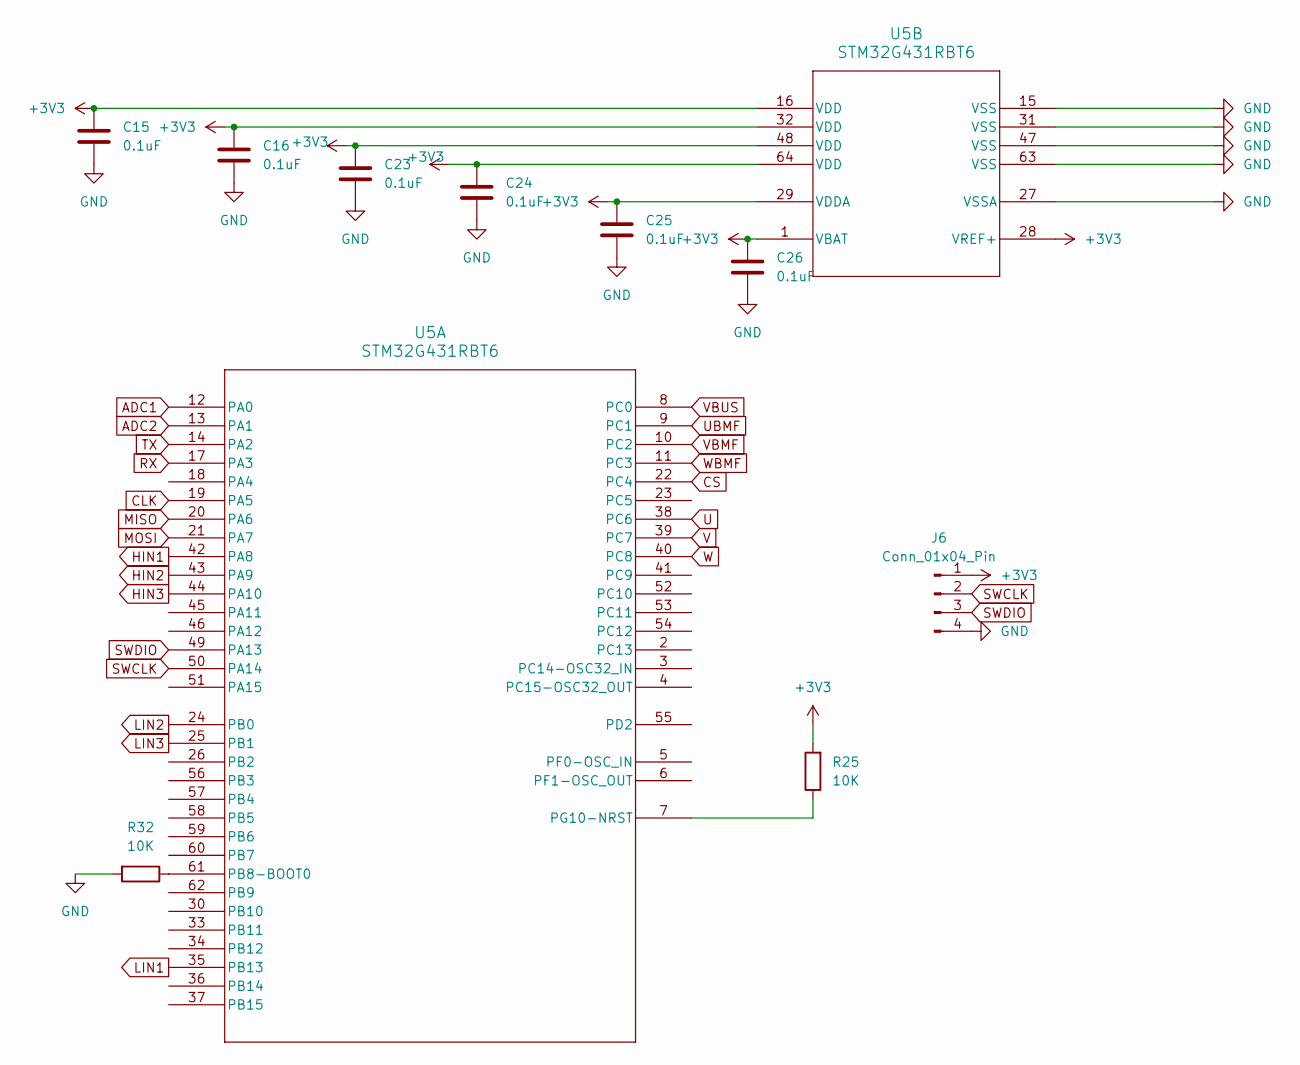
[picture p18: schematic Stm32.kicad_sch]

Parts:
C15, C16, C23, C24, C25, C26: 0.1uF; C_0805_2012Metric
J6: Conn_01x04_Pin; PinHeader_1x04_P2.54mm_Vertical
R25, R32: 10K; R_0805_2012Metric
U5: STM32G431RBT6; LQFP-64_10x10mm_P0.5mm

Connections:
+3V3: C15.1, C16.1, C23.1, C24.1, C25.1, C26.1, J6.1, R25.2, U5.1 (VBAT), U5.16 (VDD), U5.28 (VREF+), U5.29 (VDDA), U5.32 (VDD), U5.48 (VDD), U5.64 (VDD); also elsewhere on the board
ADC1: U5.12 (PA0); also elsewhere on the board
ADC2: U5.13 (PA1); also elsewhere on the board
CLK: U5.19 (PA5); also elsewhere on the board
CS: U5.22 (PC4); also elsewhere on the board
GND: C15.2, C16.2, C23.2, C24.2, C25.2, C26.2, J6.4, R32.2, U5.15 (VSS), U5.27 (VSSA), U5.31 (VSS), U5.47 (VSS), U5.63 (VSS); also elsewhere on the board
HIN1: U5.42 (PA8); also elsewhere on the board
HIN2: U5.43 (PA9); also elsewhere on the board
HIN3: U5.44 (PA10); also elsewhere on the board
LIN1: U5.35 (PB13); also elsewhere on the board
LIN2: U5.24 (PB0); also elsewhere on the board
LIN3: U5.25 (PB1); also elsewhere on the board
MISO: U5.20 (PA6); also elsewhere on the board
MOSI: U5.21 (PA7); also elsewhere on the board
unnamed: R32.1, U5.61 (PB8-BOOT0)
unnamed: R25.1, U5.7 (PG10-NRST)
RX: U5.17 (PA3)
SWCLK: J6.2, U5.50 (PA14)
SWDIO: J6.3, U5.49 (PA13)
TX: U5.14 (PA2)
U: U5.38 (PC6); also elsewhere on the board
UBMF: U5.9 (PC1); also elsewhere on the board
V: U5.39 (PC7); also elsewhere on the board
VBMF: U5.10 (PC2); also elsewhere on the board
VBUS: U5.8 (PC0); also elsewhere on the board
W: U5.40 (PC8); also elsewhere on the board
WBMF: U5.11 (PC3); also elsewhere on the board

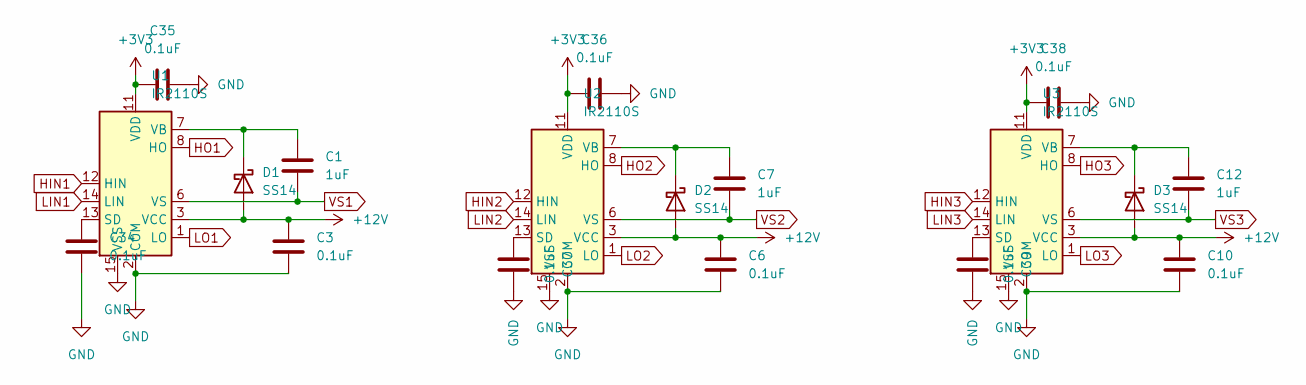
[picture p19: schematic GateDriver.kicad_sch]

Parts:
C1, C7, C12: 1uF; C_0805_2012Metric
C3, C6, C10, C34, C35, C36, C37, C38, C39: 0.1uF; C_0805_2012Metric
D1, D2, D3: SS14; D_SMA
U1, U2, U3: IR2110S; SOIC-16W_7.5x10.3mm_P1.27mm

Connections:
+3V3: C35.1, C36.1, C38.1, U1.11 (VDD), U2.11 (VDD), U3.11 (VDD); also elsewhere on the board
+12V: C3.1, C6.1, C10.1, D1.2 (A), D2.2 (A), D3.2 (A), U1.3 (VCC), U2.3 (VCC), U3.3 (VCC); also elsewhere on the board
GND: C3.2, C6.2, C10.2, C34.2, C35.2, C36.2, C37.2, C38.2, C39.2, U1.2 (COM), U1.15 (VSS), U2.2 (COM), U2.15 (VSS), U3.2 (COM), U3.15 (VSS); also elsewhere on the board
HIN1: U1.12 (HIN); also elsewhere on the board
HIN2: U2.12 (HIN); also elsewhere on the board
HIN3: U3.12 (HIN); also elsewhere on the board
HO1: U1.8 (HO); also elsewhere on the board
HO2: U2.8 (HO); also elsewhere on the board
HO3: U3.8 (HO); also elsewhere on the board
LIN1: U1.14 (LIN); also elsewhere on the board
LIN2: U2.14 (LIN); also elsewhere on the board
LIN3: U3.14 (LIN); also elsewhere on the board
LO1: U1.1 (LO); also elsewhere on the board
LO2: U2.1 (LO); also elsewhere on the board
LO3: U3.1 (LO); also elsewhere on the board
unnamed: C1.1, D1.1 (K), U1.7 (VB)
unnamed: C7.1, D2.1 (K), U2.7 (VB)
unnamed: C12.1, D3.1 (K), U3.7 (VB)
unnamed: C34.1, U1.13 (SD)
unnamed: C37.1, U2.13 (SD)
unnamed: C39.1, U3.13 (SD)
VS1: C1.2, U1.6 (VS); also elsewhere on the board
VS2: C7.2, U2.6 (VS); also elsewhere on the board
VS3: C12.2, U3.6 (VS); also elsewhere on the board

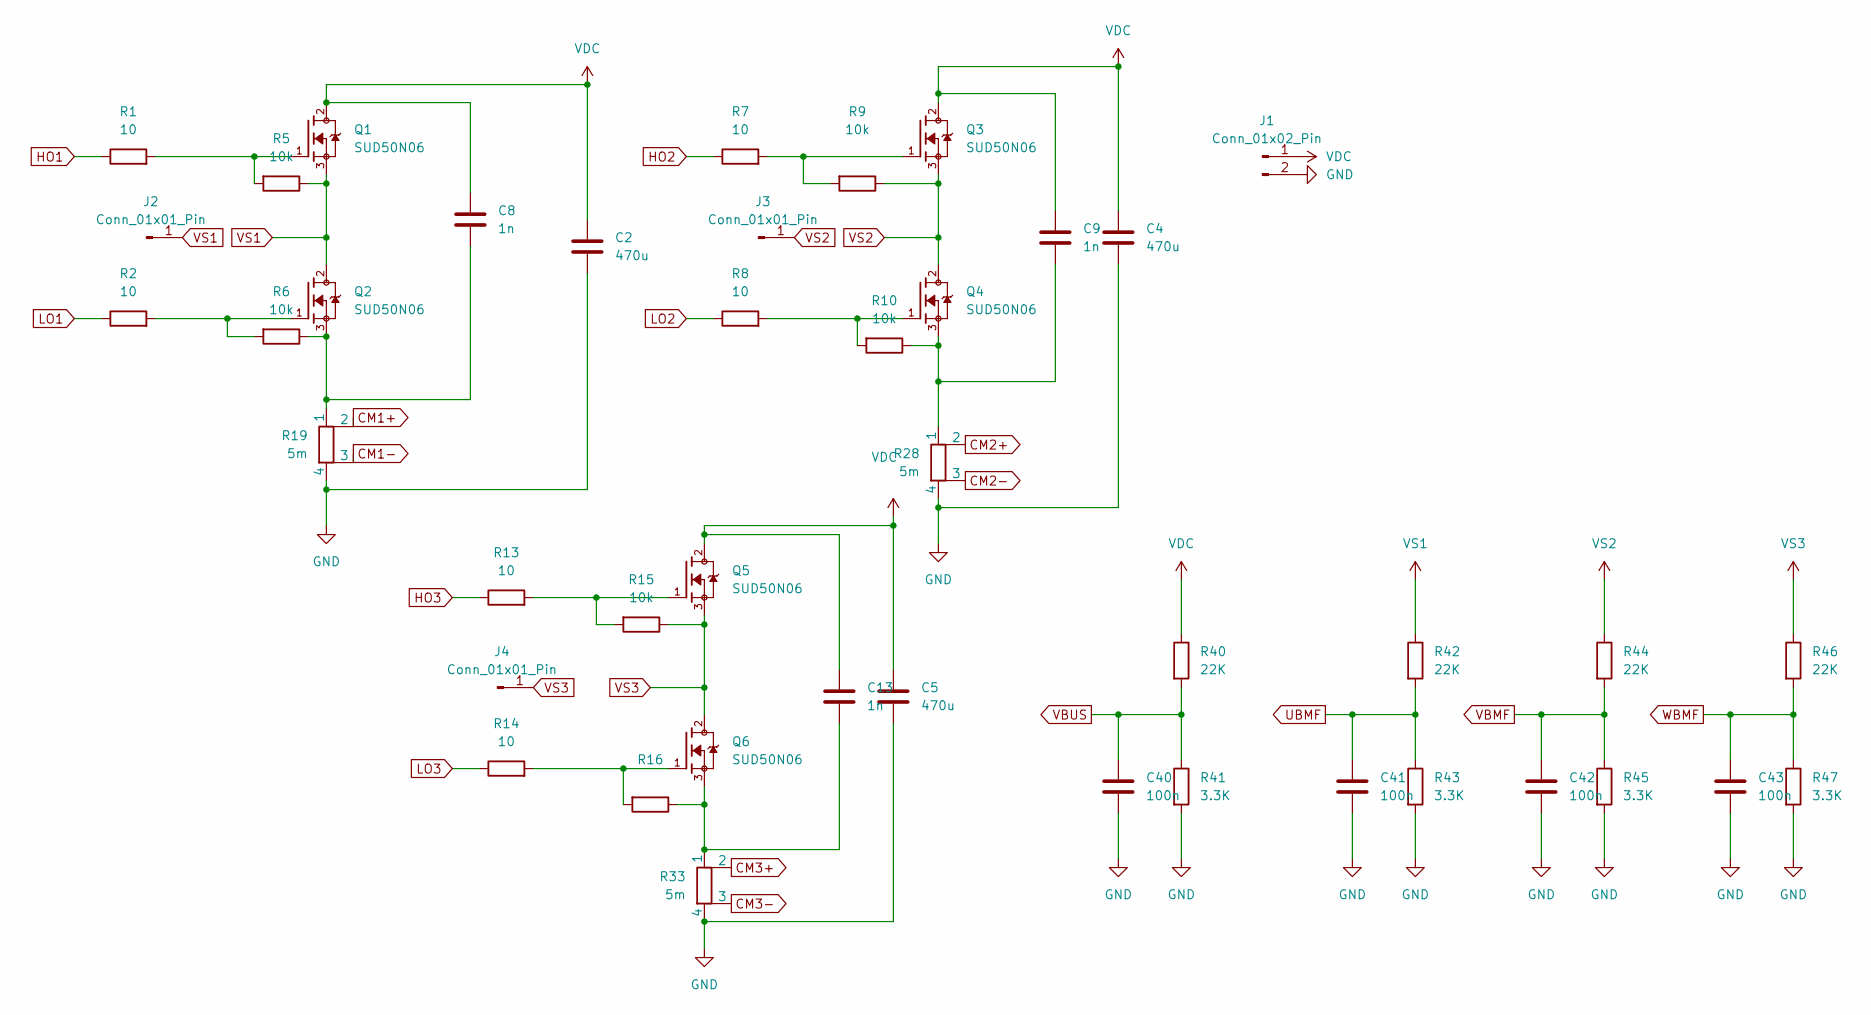
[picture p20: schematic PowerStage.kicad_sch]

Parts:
C2, C4, C5: 470u; CP_Radial_D10.0mm_P5.00mm
C8, C9, C13: 1n; C_0805_2012Metric
C40, C41, C42, C43: 100n; C_0805_2012Metric
J1: Conn_01x02_Pin; AMASS_XT60-M_1x02_P7.20mm_Vertical
J2, J3, J4: Conn_01x01_Pin; SolderWire-2sqmm_1x01_D2mm_OD3.9mm
Q1, Q2, Q3, Q4, Q5, Q6: SUD50N06; TO-252-2
R1, R2, R7, R8, R13, R14: 10; R_0805_2012Metric
R5, R6, R9, R10, R15, R16: 10k; R_0805_2012Metric
R19, R28, R33: 5m; R_Shunt_Vishay_WSK2512_6332Metric_T1.19mm
R40, R42, R44, R46: 22K; R_0805_2012Metric
R41, R43, R45, R47: 3.3K; R_0805_2012Metric

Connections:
CM1+: R19.2; also elsewhere on the board
CM1-: R19.3; also elsewhere on the board
CM2+: R28.2; also elsewhere on the board
CM2-: R28.3; also elsewhere on the board
CM3+: R33.2; also elsewhere on the board
CM3-: R33.3; also elsewhere on the board
GND: C2.2, C4.2, C5.2, C40.2, C41.2, C42.2, C43.2, J1.2, R19.4, R28.4, R33.4, R41.2, R43.2, R45.2, R47.2; also elsewhere on the board
HO1: R1.1; also elsewhere on the board
HO2: R7.1; also elsewhere on the board
HO3: R13.1; also elsewhere on the board
LO1: R2.1; also elsewhere on the board
LO2: R8.1; also elsewhere on the board
LO3: R14.1; also elsewhere on the board
unnamed: C8.2, Q2.3, R6.1, R19.1
unnamed: C9.2, Q4.3, R10.1, R28.1
unnamed: C13.2, Q6.3, R16.1, R33.1
unnamed: Q1.1, R1.2, R5.2
unnamed: Q2.1, R2.2, R6.2
unnamed: Q3.1, R7.2, R9.2
unnamed: Q4.1, R8.2, R10.2
unnamed: Q5.1, R13.2, R15.2
unnamed: Q6.1, R14.2, R16.2
UBMF: C41.1, R42.2, R43.1; also elsewhere on the board
VBMF: C42.1, R44.2, R45.1; also elsewhere on the board
VBUS: C40.1, R40.2, R41.1; also elsewhere on the board
VDC: C2.1, C4.1, C5.1, C8.1, C9.1, C13.1, J1.1, Q1.2, Q3.2, Q5.2, R40.1; also elsewhere on the board
VS1: J2.1, Q1.3, Q2.2, R5.1, R42.1; also elsewhere on the board
VS2: J3.1, Q3.3, Q4.2, R9.1, R44.1; also elsewhere on the board
VS3: J4.1, Q5.3, Q6.2, R15.1, R46.1; also elsewhere on the board
WBMF: C43.1, R46.2, R47.1; also elsewhere on the board

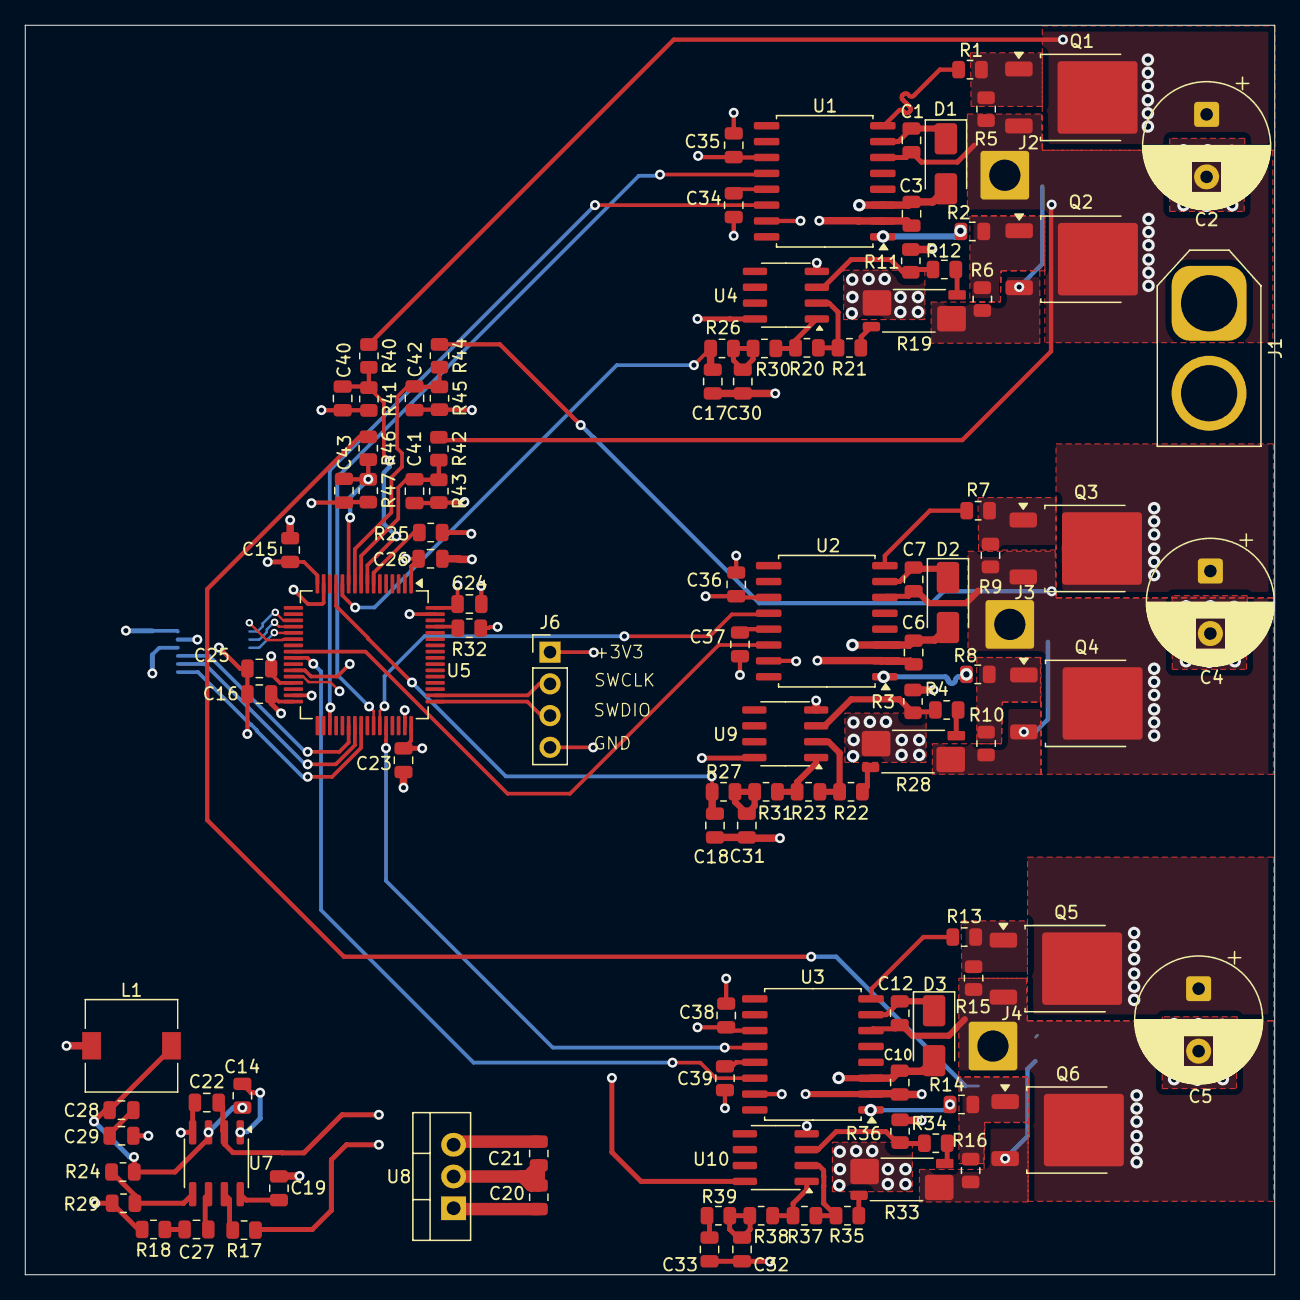
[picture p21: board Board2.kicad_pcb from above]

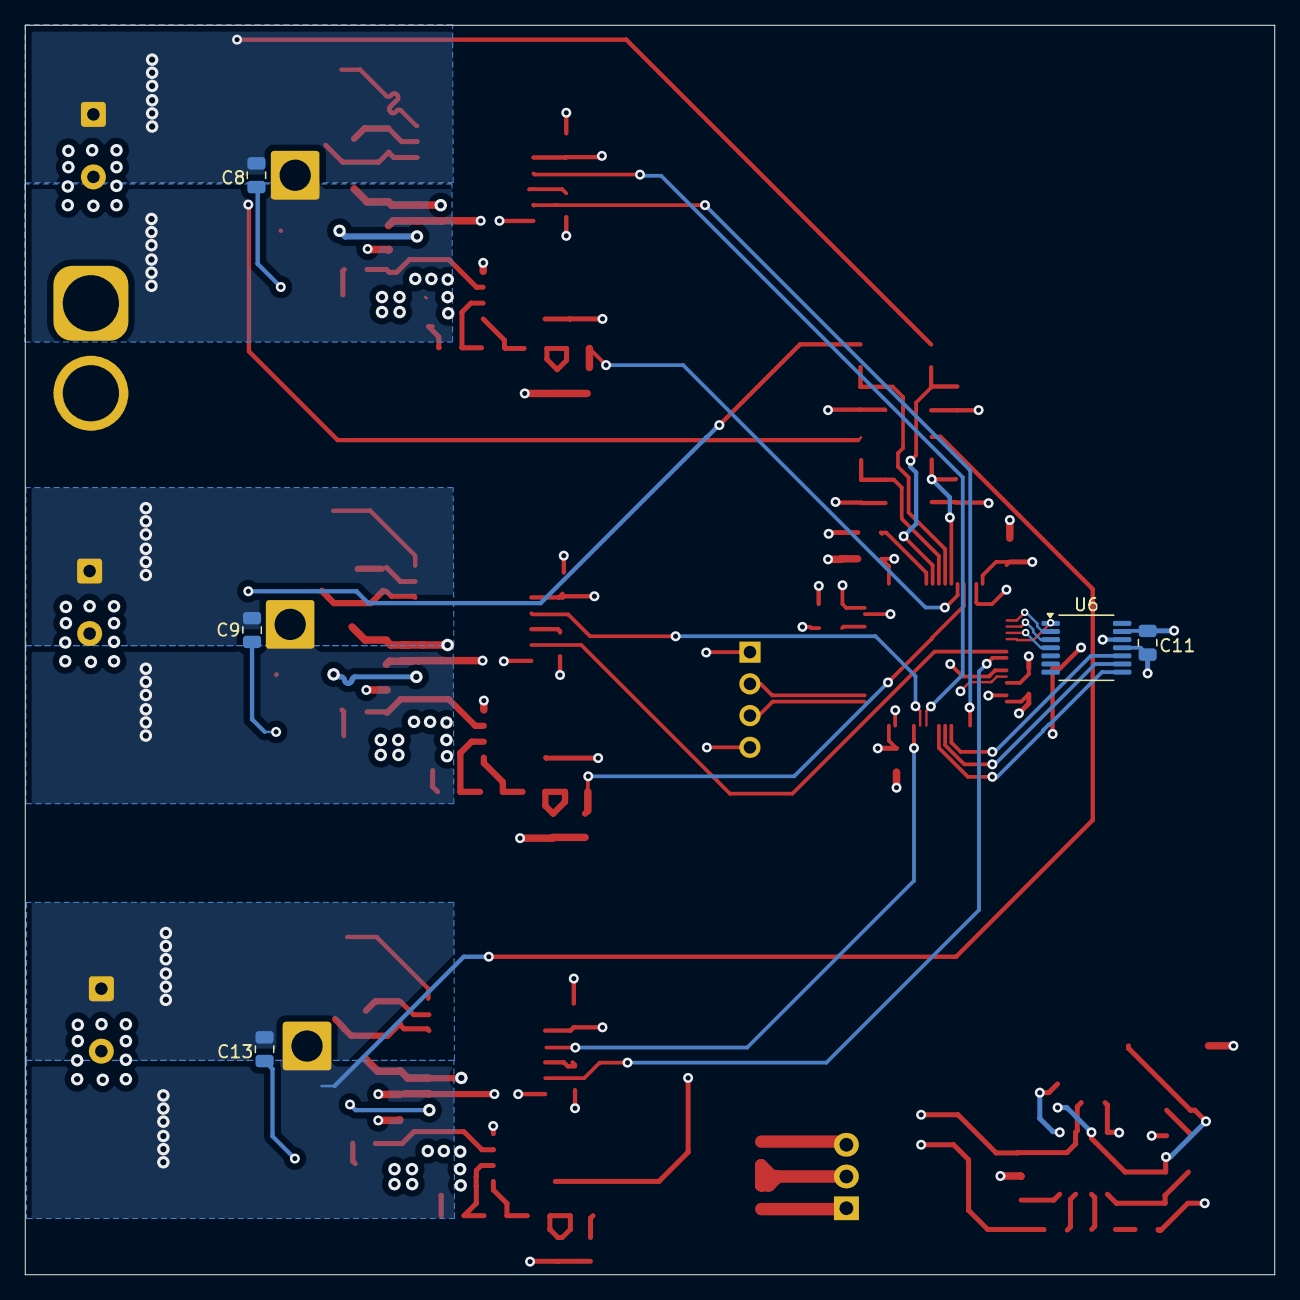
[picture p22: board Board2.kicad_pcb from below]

Board: 4 copper layers, 100.0 x 100.0 mm, 115 parts (5 on the bottom side), 78 nets.

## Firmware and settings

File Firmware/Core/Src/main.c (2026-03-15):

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
/* Includes ------------------------------------------------------------------*/
#include "main.h"

/* USER CODE BEGIN Includes */
#include "bldc.h"
/* USER CODE END Includes */

ADC_HandleTypeDef hadc1;

TIM_HandleTypeDef htim1;
TIM_HandleTypeDef htim6;
TIM_HandleTypeDef htim7;

UART_HandleTypeDef huart2;

void SystemClock_Config(void);
static void MX_GPIO_Init(void);
static void MX_ADC1_Init(void);
static void MX_TIM1_Init(void);
static void MX_USART2_UART_Init(void);
static void MX_TIM7_Init(void);
static void MX_TIM6_Init(void);
/**
  * @brief  The application entry point.
  * @retval int
  */
int main(void)
{
  /* MCU Configuration--------------------------------------------------------*/

  /* Reset of all peripherals, Initializes the Flash interface and the Systick. */
  HAL_Init();

  /* Configure the system clock */
  SystemClock_Config();

  /* Initialize all configured peripherals */
  MX_GPIO_Init();
  MX_ADC1_Init();
  MX_TIM1_Init();
  MX_USART2_UART_Init();
  MX_TIM7_Init();
  MX_TIM6_Init();
  /* USER CODE BEGIN 2 */

  BLDC_Init();

  HAL_ADCEx_Calibration_Start(&hadc1, ADC_SINGLE_ENDED);
  HAL_ADCEx_InjectedStart_IT(&hadc1);

  HAL_TIM_PWM_Start(&htim1, TIM_CHANNEL_1);
  HAL_TIMEx_PWMN_Start(&htim1, TIM_CHANNEL_1);

  HAL_TIM_PWM_Start(&htim1, TIM_CHANNEL_2);
  HAL_TIMEx_PWMN_Start(&htim1, TIM_CHANNEL_2);

  HAL_TIM_PWM_Start(&htim1, TIM_CHANNEL_3);
  HAL_TIMEx_PWMN_Start(&htim1, TIM_CHANNEL_3);

  HAL_TIM_Base_Start_IT(&htim7);
  HAL_TIM_Base_Start_IT(&htim6);


  /* USER CODE END 2 */

  /* Infinite loop */
  /* USER CODE BEGIN WHILE */


  while (1)
  {

	  if (bldc.state == BLDC_STATE_IDLE)
	        {
	            HAL_Delay(1000);

	            // Rotor Align
	            bldc.state = BLDC_STATE_ALIGN;
	            BLDC_SetDutyCycle(400);
	            BLDC_Commutate(BLDC_STEP_1);
	            HAL_Delay(500);

	            // Open Loop Rampup
	            bldc.timer_ticks = 0;
	            bldc.commutation_delay = 200;
	            BLDC_SetDutyCycle(450);
	            bldc.state = BLDC_STATE_RAMPUP;
	        }


    /* USER CODE END WHILE */

    /* USER CODE BEGIN 3 */
  }
  /* USER CODE END 3 */
}

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
/* USER CODE BEGIN 4 */

void Delay_us(uint16_t us) {
    __HAL_TIM_SET_COUNTER(&htim6, 0);
    while (__HAL_TIM_GET_COUNTER(&htim6) < us);
}

// 1khz PI Loop
void HAL_TIM_PeriodElapsedCallback(TIM_HandleTypeDef *htim)
{
    if (htim->Instance == TIM7)
    {
        if (bldc.state == BLDC_STATE_CLOSED_LOOP)
        {
            if (bldc.pi_ready) {
                bldc.pi_ready = 0;
                bldc.target_speed = 10; // Ref changes can be do here
                BLDC_Speed_PI_Controller();
            }
        }
    }
}

/* USER CODE END 4 */
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


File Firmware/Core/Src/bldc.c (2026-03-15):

/*
 * bldc.c
 *
 *  Created on: Mar 8, 2026
 *      Author: fgok5
 */

#include "bldc.h"

float PI_KP = 0.35f;
float PI_KI = 0.025f;

volatile BLDC_Controller_t bldc = {0};

extern TIM_HandleTypeDef htim1;


void BLDC_Init(void) {
    bldc.state = BLDC_STATE_IDLE;
    bldc.current_step = BLDC_STEP_1;
    bldc.current_duty = 0;

    bldc.speed_sum = 0;
        for(int i=0; i<MAF_SIZE; i++) {
            bldc.speed_history[i] = 20;
            bldc.speed_sum += 20;
        }
        bldc.speed_index = 0;

    BLDC_SetDutyCycle(0);
}

void BLDC_SetDutyCycle(uint16_t duty) {
    if (duty > BLDC_MAX_DUTY_CYCLE) duty = BLDC_MAX_DUTY_CYCLE;

    bldc.current_duty = duty;


    __HAL_TIM_SET_COMPARE(&htim1, TIM_CHANNEL_1, bldc.current_duty);
    __HAL_TIM_SET_COMPARE(&htim1, TIM_CHANNEL_2, bldc.current_duty);
    __HAL_TIM_SET_COMPARE(&htim1, TIM_CHANNEL_3, bldc.current_duty);
}



// Injected ADC Interrupt Function
void HAL_ADCEx_InjectedConvCpltCallback(ADC_HandleTypeDef *hadc)
{
    if (hadc->Instance == ADC1)
    {
        bldc.adc_vdc = HAL_ADCEx_InjectedGetValue(hadc, BLDC_ADC_VDC_RANK);
        bldc.adc_vs1 = HAL_ADCEx_InjectedGetValue(hadc, BLDC_ADC_VS1_RANK);
        bldc.adc_vs2 = HAL_ADCEx_InjectedGetValue(hadc, BLDC_ADC_VS2_RANK);
        bldc.adc_vs3 = HAL_ADCEx_InjectedGetValue(hadc, BLDC_ADC_VS3_RANK);

        bldc.virtual_neutral = (bldc.adc_vs1 + bldc.adc_vs2 + bldc.adc_vs3) / 3;

        switch (bldc.state)
        {
            case BLDC_STATE_IDLE:
        	    BLDC_SetDutyCycle(0);
   	            TIM1->CCER &= ~(TIM_CCER_CC1E | TIM_CCER_CC1NE |
            	                TIM_CCER_CC2E | TIM_CCER_CC2NE |
            	                TIM_CCER_CC3E | TIM_CCER_CC3NE);
                break;

            case BLDC_STATE_ALIGN:
                // Rotor Align
            	// The ISR just waits for the mechanical rotor to align with the stator.
                break;

            case BLDC_STATE_RAMPUP:
            	bldc.timer_ticks++;

            	                if (bldc.timer_ticks >= bldc.commutation_delay)
            	                {
            	                    bldc.timer_ticks = 0;

            	                    BLDC_CommutationStep_t next_step = (bldc.current_step % 6) + 1;
            	                    BLDC_Commutate(next_step);

            	                    if (bldc.commutation_delay > 25) {
            	                        bldc.commutation_delay--;
            	                    }
            	                    else {

            	                        bldc.state = BLDC_STATE_CLOSED_LOOP;
            	                        bldc.blanking_counter = BLDC_ZCD_BLANKING_COUNT;
            	                    }
            	                }
                break;

            case BLDC_STATE_CLOSED_LOOP:
            	bldc.stall_counter++;
            	bldc.step_timer_ticks++;

            					if (bldc.stall_counter > 2000)
            	                {
            	                    bldc.state = BLDC_STATE_IDLE;
            	                    BLDC_SetDutyCycle(0);
            	                    bldc.stall_counter = 0;
            	                    break;
            	                }

            	                if (bldc.blanking_counter > 0) {
            	                    bldc.blanking_counter--;
            	                } else {
            	                    BLDC_CheckZCD();
            	                }
            	                bldc.pi_ready = 1;
                break;

            case BLDC_STATE_FAULT:
                BLDC_SetDutyCycle(0);
                HAL_TIM_PWM_Stop(&htim1, TIM_CHANNEL_1);
                HAL_TIM_PWM_Stop(&htim1, TIM_CHANNEL_2);
                HAL_TIM_PWM_Stop(&htim1, TIM_CHANNEL_3);
                break;
        }
    }
}

// 6-Step Commutate

void BLDC_Commutate(BLDC_CommutationStep_t step)
{

	bldc.last_step_time = bldc.step_timer_ticks;
	bldc.step_timer_ticks = 0;

	bldc.current_step = step;
	bldc.stall_counter = 0;
    uint32_t blank = bldc.last_step_time / 4;
    bldc.blanking_counter = (uint16_t)((blank < 1) ? 1 : blank);

    TIM1->CCER &= ~(TIM_CCER_CC1E | TIM_CCER_CC1NE |
                    TIM_CCER_CC2E | TIM_CCER_CC2NE |
                    TIM_CCER_CC3E | TIM_CCER_CC3NE);

    switch (step)
    {
        case BLDC_STEP_1:
            // Faz A: PWM (High), Faz B: GND (Low), Faz C: Float
            TIM1->CCR1 = bldc.current_duty;
            TIM1->CCR2 = 0;
            TIM1->CCER |= (TIM_CCER_CC1E | TIM_CCER_CC1NE | TIM_CCER_CC2E | TIM_CCER_CC2NE);
            break;

        case BLDC_STEP_2:
            // Faz A: PWM (High), Faz C: GND (Low), Faz B: Float
            TIM1->CCR1 = bldc.current_duty;
            TIM1->CCR3 = 0;
            TIM1->CCER |= (TIM_CCER_CC1E | TIM_CCER_CC1NE | TIM_CCER_CC3E | TIM_CCER_CC3NE);
            break;

        case BLDC_STEP_3:
            // Faz B: PWM (High), Faz C: GND (Low), Faz A: Float
            TIM1->CCR2 = bldc.current_duty;
            TIM1->CCR3 = 0;
            TIM1->CCER |= (TIM_CCER_CC2E | TIM_CCER_CC2NE | TIM_CCER_CC3E | TIM_CCER_CC3NE);
            break;

        case BLDC_STEP_4:
            // Faz B: PWM (High), Faz A: GND (Low), Faz C: Float
            TIM1->CCR2 = bldc.current_duty;
            TIM1->CCR1 = 0;
            TIM1->CCER |= (TIM_CCER_CC2E | TIM_CCER_CC2NE | TIM_CCER_CC1E | TIM_CCER_CC1NE);
            break;

        case BLDC_STEP_5:
            // Faz C: PWM (High), Faz A: GND (Low), Faz B: Float
            TIM1->CCR3 = bldc.current_duty;
            TIM1->CCR1 = 0;
            TIM1->CCER |= (TIM_CCER_CC3E | TIM_CCER_CC3NE | TIM_CCER_CC1E | TIM_CCER_CC1NE);
            break;

        case BLDC_STEP_6:
            // Faz C: PWM (High), Faz B: GND (Low), Faz A: Float
            TIM1->CCR3 = bldc.current_duty;
            TIM1->CCR2 = 0;
            TIM1->CCER |= (TIM_CCER_CC3E | TIM_CCER_CC3NE | TIM_CCER_CC2E | TIM_CCER_CC2NE);
            break;
    }

    //COM (Commutation) Event trigger
    TIM1->EGR |= TIM_EGR_COMG;
}
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

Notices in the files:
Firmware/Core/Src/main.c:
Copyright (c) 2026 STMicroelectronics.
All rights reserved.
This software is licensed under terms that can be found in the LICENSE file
